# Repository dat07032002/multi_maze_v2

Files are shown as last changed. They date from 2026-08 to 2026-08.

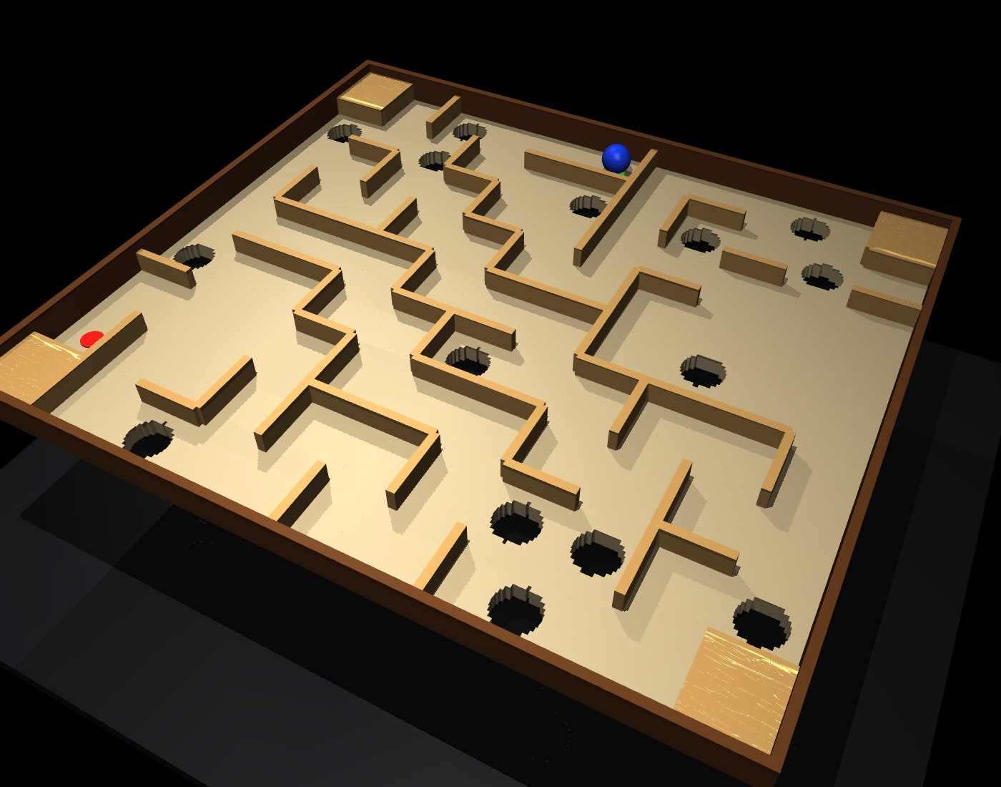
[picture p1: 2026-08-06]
maze_design/maze_final_iso.png

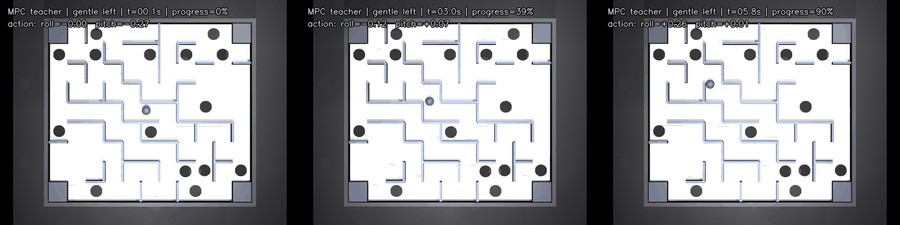
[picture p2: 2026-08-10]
tmp/pdfs/current_design_assets/gentle_left-mpc-teacher-strip.jpg

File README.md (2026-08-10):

# Multi Maze V2: board vision, maze design, and tilt servos

A ball-maze robot built from scratch, standalone Python, no ROS.

Six parts exist today:

- **Vision** -- a calibrated overhead camera and four AprilTags give the board's
  two tilt angles; a hybrid blue-colour/circle detector locates a 5.5 mm-radius
  marble in metric board coordinates.
- **Maze design** -- generators, a rescaler, an STL exporter, and validators for
  the printed 256 x 226 mm insert. See [`maze_design/README.md`](maze_design/README.md).
- **Servos** -- a from-scratch FEETECH STS3215 bus driver and command tools.
- **IMU and system identification** -- an ESP32 streams BNO086 tilt at 200 Hz,
  and `tools/sysid_actuator.py` measures the counts-to-angle mapping the servo
  contract needs. See [`firmware/esp32_imu/README.md`](firmware/esp32_imu/README.md).
- **Camera maze planning** -- the live image is rectified into board millimetres,
  segmented into walls and holes, inflated for the marble radius, and planned
  with clearance-aware A*.
- **Real model-based RL** -- safe random exploration collects real transitions,
  a probabilistic PyTorch ensemble learns dynamics on the local GPU, and CUDA
  CEM plans bounded tilt sequences. Training and checkpoint replacement happen
  between physical episodes; no simulator or sim-to-real transfer is used.

The main live application is standalone OpenCV and does **not** require ROS:

```bash
python3 tools/manual_tilt_angle.py
```

Press `z` while the board is level to save the angle reference. Press `q` or
`Esc` to quit.

## What the viewer reports

The window is camera-undistorted and displays:

- `alpha`: rotation about the board X hinge, in degrees;
- `beta`: rotation about the subsequent board Y hinge, in degrees;
- detected tag IDs and pose reprojection error;
- blue-marble centre `(x, y)` in millimetres and detector confidence;
- the magenta board boundary and metric coordinate frame;
- `O (0,0) mm` at the lower-left board corner, near tag 3;
- red `+X` toward the lower-right corner/tag 1;
- green `+Y` toward the upper-left corner/tag 0.

The ball position is its centre projected onto the plane `z = 5.5 mm`, not the
point where it touches the board.

## Current hardware and calibration

| Item | Current value |
| --- | --- |
| Camera | See3CAM_24CUG, auto-selected when available |
| Capture | 1920 x 1200 MJPG, resized uniformly to 1280 x 800 |
| Calibration model | Kannala-Brandt fisheye |
| Calibration RMS | 0.390 px over 88 views / 5108 points |
| Board | 256 x 226 mm |
| Tags | Four 18 mm `tag36h11` tags, IDs 0–3 |
| Marble | Blue, 5.5 mm radius |
| Pose requirement | Four known tags by default |
| Pose rejection | Reprojection RMS greater than 4 px |
| Tilt servos | Two FEETECH STS3215, ids 1 and 2, 1 Mbps on `/dev/ttyUSB0` |
| Servo mode | Position (register 33 = 0), 0-4095 counts over 360 deg |
| IMU | SparkFun BNO086, I2C on ESP32 GPIO16/17, game rotation vector @ 200 Hz |
| IMU link | ESP32-D0WD-V3 on CP2102, 115200; ports resolved by USB id |
| Directional calibration | alpha +0.00477 deg/count on servo 2; beta -0.00442 on servo 1 |
| Level at | servo 1: 2173 counts; servo 2: 2013 counts |
| Commandable tilt | ±4.0°, calibrated headroom ±5.42° / ±5.78° |
| Mechanical travel | roll ±7.00°, pitch ±8.36° |
| Backlash (operational) | **~1.35°** — the dominant error by ~7x |
| Command resolution | 40 counts (~0.19°) practical floor; under 20 is unusable |

The checked-in tag coordinates in
[`calib/board_tags.json`](calib/board_tags.json) are **derived from the maze
layout's tag pads, not caliper-measured** (`"measured": false`). Tags are glued
to the top of the corner pads, so `z_m = 0.011`: the pad top is 8 mm above the
playing surface and the tag is 3 mm thick. All four shift equally, so alpha and
beta are unaffected, but marble coordinates are -- the ray/plane intersection
depends on that height. Measuring the installed tags remains the route to
absolute accuracy.

The saved zero in [`calib/board_zero.json`](calib/board_zero.json) is specific
to the current camera pose. Re-zero after the camera, board mount, or lens has
moved.

## Installation

Python 3.10 was used during development. On a regular Python environment:

```bash
python3 -m venv .venv
source .venv/bin/activate
python3 -m pip install -r requirements.txt
python3 -m pytest -q
```

OpenCV must contain `cv2.aruco`; this is why the requirements use the contrib
distribution. The main live viewer accesses the camera directly with OpenCV.
The older calibration/monitoring tools that import `rclpy` additionally require
a sourced ROS 2 installation and `cv_bridge`.

Install the optional local-GPU RL dependencies after the NVIDIA driver is
healthy:

```bash
python3 -m pip install -r requirements-rl.txt
python3 tools/rl_preflight.py
```

## Everyday commands

Run the combined angle and ball viewer:

```bash
python3 tools/manual_tilt_angle.py
```

Cross-check the camera angles against the BNO086 while also viewing ball
coordinates. With the powered board physically level, press `z` once to save a
joint reference, then hold several positive and negative tilts on each axis:

```bash
python3 tools/camera_imu_check.py
```

The checker records comparisons only while the IMU is settled and reports
bias, RMSE, and maximum error when it exits. It also displays `FUSED`: IMU
increments provide the low-latency motion estimate and valid camera poses pull
that estimate back to an absolute reference with a 0.5 s time constant. Camera
residuals above 2° are rejected by default. Both values are configurable with
`--fusion-time-constant` and `--fusion-camera-gate`.

Drive the calibrated board from the keyboard while logging camera, IMU, and
fused angles, their difference, servo counts, targets, and pose quality:

```bash
python3 tools/keyboard_motor_compare.py
```

Use `A/D` for alpha, `S/W` for beta, `0` for the captured level position, and
`q` to quit and release torque. Runs are stored under
`artifacts/keyboard_compare/`.

Use the validated direction-dependent motor calibration when precise static
positioning matters:

```bash
python3 tools/keyboard_motor_compare.py \
  --directional-calibration calib/directional_motor.json \
  --fused-trim
```

This table is tied to the saved joint zero and must be regenerated after
re-zeroing or changing the linkage. Fit a new candidate from a settled fused
bidirectional run with `tools/fit_directional_motor.py <run-directory>`.
`--fused-trim` adds a slow static correction after each move: it waits for the
IMU to settle, corrects both axes through the measured coupled Jacobian, caps
each correction at 80 counts, and stops after at most six attempts. Its 0.10°
default tolerance is below the rig's measured 0.19° reliable command step.

Build a route from the maze that is physically under the camera, rather than
from a saved maze-design file:

```bash
# Use the detected blue ball as START and click the GOAL.
python3 tools/plan_camera_maze.py --click

# Or supply both endpoints in board millimetres.
python3 tools/plan_camera_maze.py \
  --start-mm 30 200 --goal-mm 220 25 --no-window
```

The mapper aligns 20 frames through the four AprilTags, rectifies the playing
surface at 2 pixels/mm, takes a temporal median, and segments yellow walls and
circular black holes. It plans on a 1 mm grid after inflating every obstacle by
the 5.5 mm ball radius plus a 0.5 mm safety margin. Clearance-weighted A* and
line-of-sight pruning produce 5 mm-spaced training waypoints. Each run writes
the top-down image, masks, route overlay, and metric `map.json` under
`artifacts/camera_maze/<timestamp>/`. Use `--auto-endpoints` only as a mapping
smoke test; training should specify the intended start/goal or click them.

Run continuous real-hardware training from an empty replay:

```bash
python3 tools/run_real_rl.py \
  --execute \
  --continuous-training \
  --fresh-replay \
  --policy explore
```

`--execute` opens the servo bus but does not move it. Wait for green health and
press Space once to authorize the first episode. `q`/Escape always levels the
board, releases torque, saves replay, and stops. The controller then operates
without a key press between ordinary episodes:

- fresh data uses smooth random targets over the full ±4° envelope;
- commands are independently clipped to ±4° and slew-limited to 0.5° per 5 Hz
  control step;
- the first dynamics model needs at least 300 total transitions and 120 with
  measured motion;
- dynamics bootstrap batches are balanced 50/50 between moving and stationary
  transitions so static samples cannot overwhelm the command response;
- after a model is available, four CEM episodes alternate with one random
  exploration episode;
- a CEM episode stationary for 3 s changes to `RECOVERY_EXPLORE` for the rest
  of that episode, without prescribing a hard-coded breakaway angle;
- every additional 100 transitions schedules another 50-epoch background
  update and activates it only at an episode boundary.

To resume, provide both the saved replay and latest completed checkpoint;
never select an update whose checkpoint was interrupted:

```bash
python3 tools/run_real_rl.py \
  --execute --continuous-training \
  --replay artifacts/rl/runs/<run>/replay_after_run.npz \
  --checkpoint artifacts/rl/runs/<run>/online_models/update_NNN/dynamics.pt \
  --policy cem
```

The live phases are operational state:

| Phase | Meaning |
| --- | --- |
| `EXPLORE` | scheduled full-range random data collection |
| `RL_EPISODE` | CEM is planning through the learned ensemble |
| `RECOVERY_EXPLORE` | CEM stayed stationary for 3 s; random recovery took over |
| `CONFIRMING_DROP` | detection is stale; the board is level while absence is debounced |
| `ARMED_FOR_RELOAD` | a real drop is confirmed; calibrated backward tilt is held |
| `FIXED_BRAKING` | the reappearing marble is being slowed |
| `RESET_SETTLING` | level board and speed below 12 mm/s are being confirmed |
| `TRAINING_WAIT` | reset is complete but an atomic model update is finishing |

Judge learning across episodes using maximum route progress minus episode-start
progress, cross-track error, return, goal count, and the fraction of CEM
episodes needing recovery. Validation loss alone is not proof that the physical
controller improved.

Select a camera explicitly or run without a GUI:

```bash
python3 tools/manual_tilt_angle.py --camera 2
python3 tools/manual_tilt_angle.py --zero-on-start --no-window
```

Record a new 500-frame detector dataset at 10 Hz:

```bash
python3 tools/record_ball_dataset.py --frames 500
```

Record even when only three tags are visible (diagnostics only):

```bash
python3 tools/record_ball_dataset.py --frames 500 --min-tags 3
```

Generated frames, masks, JSONL measurements, manifests, and summaries are saved
under `artifacts/ball_capture/<timestamp>/`. This directory is ignored by Git
because raw captures are large.

Bring up the IMU and capture the level reference (do this before any servo
moves, and before anything disturbs the plate):

```bash
python3 tools/imu_monitor.py --seconds 20        # noise and drop check
python3 tools/imu_monitor.py --capture-zero --check-torque-shift
```

Measure the servos against the IMU, then fit the contract:

```bash
python3 tools/sysid_actuator.py --dry-run        # preflight, commands no motion
python3 tools/sysid_actuator.py
python3 tools/fit_sysid.py artifacts/sysid/<stamp>/sysid.json
```

Run all synthetic tests:

```bash
python3 -m pytest -q
```

## How it works

### Board angle

1. Detect known AprilTag IDs in grayscale with OpenCV ArUco.
2. Acquire/recover tags on the native 1920 x 1200 frame with
   `CORNER_REFINE_APRILTAG`, then track them in small native-resolution ROIs;
   perform a periodic full scan every 15 frames.
3. Undistort tag pixels with the calibrated Kannala-Brandt camera model.
4. Match pixels to each tag's known board-frame corners.
5. Solve the board-to-camera transform with iterative `solvePnP`.
6. Compare rotation with the saved level reference.
7. Extract angles using the simulator-compatible hinge order
   `R = Rx(alpha) @ Ry(beta)`.

### Marble position

1. Project the board boundary into the image and reject pixels outside it.
2. Exclude expanded tag footprints, which can look blue under the camera's
   fixed white balance.
3. Form broad and strict blue masks using HSV plus BGR channel separation.
4. Clean small mask noise and score contour candidates by strict-blue coverage,
   circularity, and expected projected radius.
5. Use Hough-circle edge recovery when a marble touching a rail or tool merges
   into a larger blue component. When colour already identifies the marble,
   refine the circle only in a small local crop rather than scanning the board;
   while no colour anchor exists, throttle expensive board-wide recovery to
   every fifth frame.
6. Prefer candidates near the previous valid position and reject impossible
   frame-to-frame jumps.
7. Convert the chosen distorted pixel to a calibrated ray and intersect it with
   the board-frame marble-centre plane `z = radius`.
8. Apply an exponential moving average to the reported board `(x, y)`.

Detection remains on the calibrated raw frame. The viewer image and every
overlay are mapped into the same undistorted pixel space, so visualization does
not alter the measurement path.

### Board angle from the IMU

A second, independent path to the same two angles, used as ground truth for
system identification because it samples far faster than the camera.

1. The ESP32 reads the BNO086's game rotation vector at 200 Hz over I2C.
2. Quaternions cross the link as Q14 fixed point in a 17-byte CRC-checked frame.
3. The host converts quaternion to rotation matrix and extracts alpha and beta
   with the **same** `angles_from_rotation` the camera path uses, so the two are
   directly comparable rather than two conventions that happen to agree.
4. Angles are reported relative to a level reference captured in place, using
   `zero.T @ current` -- the convention `BoardPoseEstimator` already uses.

Dropped frames are counted and surfaced, never interpolated over: a missing
report during a step response is a hole in the measurement, not a value to
invent.

### Actuator system identification

`tools/sysid_actuator.py` measures what the servo contract refuses to guess, in
a deliberate order:

1. **Axis discovery** -- move each servo alone and see which angle responds.
   Produces the sign, the axis assignment, and the 2x2 cross-coupling matrix.
   Runs first because nothing else is safe until the signs are known, and
   because significant coupling would invalidate the contract's independent-axis
   shape before any effort is spent fitting it.
2. **Static sweep** -- a load-guarded staircase gives gain, offset, and the
   linearity residual.
3. **Hysteresis** -- the same staircase in reverse gives backlash and deadband.
4. **Step response** -- unramped steps at 200 Hz give latency, rise time, and
   peak rate, with half the measured link round-trip subtracted so the latency
   describes the servo rather than the USB cable.

`tools/fit_sysid.py` writes the contract only when the measurement supports the
linear model it encodes. Failing linearity, plausibility, or coupling checks
produces `measured=False`, which keeps `angle_to_counts` raising -- a contract
that claims to be measured and is not would be worse than one that refuses.

## Repository layout

```text
calib/                         camera, board, zero, and printable tag files
contract/servo_contract.py     policy action -> board angle -> servo counts
docs/PROJECT_STATUS.md         work completed, evidence, limits, next steps
firmware/esp32_imu/            ESP32 sketch streaming BNO086 tilt
tag_vision/core/board_geometry.py
tag_vision/core/board_pose.py
tag_vision/core/ball_detection.py
tag_vision/core/angle_fusion.py complementary camera + IMU angle estimator
tag_vision/hardware/sts3215.py FEETECH bus driver
tag_vision/hardware/motion.py  load-guarded point-to-point moves
tag_vision/hardware/imu.py     BNO086 frame reader
tag_vision/control/tilt.py     board angle -> counts, backlash fed forward
tag_vision/planning/           camera maze map + clearance-aware route planner
tag_vision/rl/                 replay, task, safety, dynamics, CEM, exploration
tools/manual_tilt_angle.py     standalone live viewer
tools/camera_imu_check.py      settled camera-vs-IMU angle cross-check
tools/keyboard_motor_compare.py keyboard motor control + angle comparison log
tools/plan_camera_maze.py      live metric map and route generation
tools/run_real_rl.py           continuous real-hardware MBRL runner
tools/train_rl_dynamics.py     offline/background ensemble trainer
tools/rl_preflight.py          GPU, geometry, calibration, and port checks
tools/record_ball_dataset.py   standalone data recorder
tools/imu_monitor.py           IMU bring-up and level-zero capture
tools/sysid_actuator.py        actuator system identification
tools/fit_sysid.py             sysid run -> servo calibration
tools/validate_backlash.py     measures whether compensation actually helps
tools/*.py                     calibration, tag, servo, and ROS utilities
test/                          synthetic geometry, pose, detector, IMU, fit tests
```

## Known limitations

- Four coplanar tags give low noise, but out-of-plane tilt remains more weakly
  conditioned than translation. Known-angle physical validation is still
  required before treating angle values as ground truth.
- Using three tags can keep a pose alive during occlusion, but the tested
  `(0,1,3)` subset shifted alpha/beta by roughly `+0.47°/+0.20°` relative to
  the four-tag solution. The production default therefore requires four tags.
- Blue appearance thresholds were tuned for this camera and lighting. Major
  lighting, exposure, white-balance, board-colour, or marble-colour changes
  require fresh validation.
- The 98% recovery measured during development was an unlabeled replay with a
  blue handling tool present. It demonstrates improved recovery, not a final
  true-positive rate. A labeled, freely moving marble dataset is the next
  validation milestone.
- There is no fixed-frame tag. Moving the camera invalidates the saved level
  reference and requires pressing `z` again.
- The 2026-08-10 camera cross-check covered commanded ±4° on both axes. At the
  four endpoints camera-vs-IMU RMSE was 0.145° alpha and 0.109° beta. The
  independent sensors therefore agree well enough for complementary fusion,
  but both also exposed direction-dependent mechanical lost motion that the
  current single linear motor mapping cannot remove.
- **The calibration is valid over the range it was swept** (±1200 counts,
  roughly ±5.5°) and must not be extrapolated past it. Within that range a
  straight line holds well -- 12° of span at under 2% residual -- so the
  nonlinear form once thought necessary is not.
- **Absolute level is repeatable to about 0.4°.** The fitted centre moved 85
  counts between two consecutive sweeps with no mechanical change. Relative
  moves are considerably more trustworthy than absolute pose.
- **Commands under 20 counts do not reliably keep their sign.** 40 counts
  (~0.19°) is the practical floor, 80 is repeatable to a few percent. Any
  controller or policy step finer than that is commanding noise.
- **Backlash is the dominant error, at ~1.35° unconditioned.** That is roughly
  seven times the model residual (0.23°), the command resolution (0.19°) and the
  IMU noise (0.006°) combined. It is deterministic, not random: approached
  consistently from one side the axes repeat to 0.03°. Static positioning should
  condition its approach and gets a 40x more precise result; dynamic control
  must feed the lost motion forward instead -- about 277 counts on roll, 269 on
  pitch, injected at a direction reversal. **Simulators must use the
  unconditioned figure**, or the model will be far more precise than the board.
- The IMU level zero is captured **in place**, relying on the board being
  physically level with the IMU already mounted. That removes the need to
  measure a mount offset, but it is perishable: bumping the plate or re-mounting
  the sensor invalidates it, and re-levelling by eye reintroduces exactly the
  offset the approach avoids.
- The straight line in `AxisCalibration` holds within ±1.4°, where the model
  error (0.057°/0.071° rms) is well under one 40-count command. It is not a
  general claim about the linkage, which is a crank and loses authority further
  out; a nonlinear form is the eventual answer if the maze needs more tilt.
- **The ESP32 serial link is unreliable above 115200 and re-delivers frames.**
  Flash reads at 921600 and 460800 both stalled at exactly `0x6000`, and over 5 s
  the port yielded 1298 frames' worth of bytes when the device had sent 1000.
  The reader deduplicates on `(seq, esp_micros)`; telemetry and reflashing stay
  at 115200.
- The See3CAM negotiates 1920×1200 MJPEG at 60 FPS through direct V4L2, but the
  sequential vision pipeline processes roughly 16–19 FPS while doing pose,
  ball, route, viewer, and occasional CEM work. This is sufficient for the
  current 5 Hz controller. Camera acquisition FPS is not replay frequency.
- `--tag-detection calibrated` is an experimental A/B option that runs AprilTag
  detection on the resized 1280×800 frame. A live 2026-08-10 test improved
  processing from 22.7 to 26.0 FPS but produced 0 accepted poses at the 4 px
  reprojection gate in that view; production remains native 1920×1200 tag
  detection. The camera's native 1280×720 mode has a different aspect ratio and
  requires a separate intrinsic calibration, level zero, maze map, and caliper
  validation.
- Early online models trained from mostly stationary replay falsely predicted
  motion at zero command and selected small CEM actions. First activation is
  now gated on 120 moving transitions, training bootstraps are balanced,
  periodic exploration remains active, and sustained stationary CEM control
  falls back to random recovery. Physical episode progress remains the
  acceptance metric.

See [the project status](docs/PROJECT_STATUS.md) for detailed measurements and
the remaining validation plan.

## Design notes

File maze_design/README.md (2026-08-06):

# Maze design

## Current maze

**`maze_256x226`** — 256 × 226 mm, 15 holes, 118 waypoints, route 1023 mm.
This is the one the rest of the project targets.

| File | What |
| --- | --- |
| `maze_256x226.json` | **Source of truth.** Layout in metres, origin lower-left. |
| `maze_256x226_roles.json` | Hole roles by index: 14 `block`, 1 `dodge` |
| `maze_256x226.stl` | Printable, single colour, millimetres |
| `maze_256x226_floor.stl` | Plate only, z 0 → 3 mm |
| `maze_256x226_walls.stl` | Walls and tag pads, z 3 → 11 mm |
| `maze_256x226.png` | Top-down render |
| `maze_256x226_3d.png` | Shaded 3-D render |

Everything but the JSON is regenerated by the pipeline below, so treat the STLs
and PNGs as build output.

## Pipeline

```bash
python3 maze_design/rescale_maze.py --width 256 --height 226   # layout
python3 maze_design/export_stl.py  maze_design/maze_256x226.json          # one body
python3 maze_design/export_stl.py  maze_design/maze_256x226.json --split  # two colours
python3 maze_design/check_stl.py   maze_design/maze_256x226.json --split  # validate
python3 maze_design/render_maze.py maze_design/maze_256x226.json          # 2-D
python3 maze_design/render_3d.py   maze_design/maze_256x226.stl           # 3-D
```

`check_stl.py` is not optional. Mesh statistics alone cannot tell a correct maze
from one whose holes were never cut, and an earlier export shipped 15 hole
surrounds with inverted normals while passing every structural test. It
ray-casts against the layout and requires a **positive** winding, which is what
catches an inside-out solid.

## Geometry

| | |
| --- | --- |
| Playing area | 256 × 226 mm, 11 × 9 cells |
| Cell pitch | 23.273 × 25.111 mm |
| Corridor | 20.273 × 22.111 mm clear |
| Walls | 3 mm thick, 8 mm tall |
| Floor | 3 mm; total print height 11 mm |
| Holes | 15, radius 7.5 mm |
| Tag pads | Corner cells, solid, top at 11 mm |
| Ball | 5.5 mm radius is authoritative; the layout's 6.0 mm is design margin |

Tags are **glued** to the pad tops, so the tag face sits 11 mm above the playing
surface — that is `z_m` in `calib/board_tags.json`. `--pocket` cuts a recess
instead (face at 8 mm), but it is not the default: the pad is one cell wide, so
a pocket for a 23 mm tag leaves 0.14 mm of frame and, because corner pads sit on
the board edge, opens to the outside.

## Why rescale rather than regenerate

`maze_final.json` was **not** produced by `generate_maze.py` — that script emits
`maze_v1.json` with 23 horizontal wall runs against the final's 76. The pipeline
that made it is not in this repository, so regenerating from seed 1626 yields a
different maze. `rescale_maze.py` scales the existing layout instead, which
keeps the topology identical.

Positions scale; wall thickness, wall height, hole radius, and ball radius do
not — those are set by the printer and the marble. The corridors absorb the
difference.

## Historical files

Kept for provenance, not used by anything current:

- `maze_final.*` — the 259 × 229 predecessor `maze_256x226` was scaled from
- `maze_print*.stl` — its STLs, scaled in **metres**; a slicer reads them as a
  0.26 mm speck
- `print/maze_final/` — an older 17-hole bundle, superseded. Its `route.json`
  (122 points) does not match any current layout
- `base_1626.*`, `maze_v1.*`, `sample_1..12.*`, `samples*.png` — earlier
  candidates and contact sheets

## Broken scripts

`view_maze.py`, `orbit_maze.py`, `playtest_maze.py`, and `generate_samples.py`
`sys.path.insert` into `~/Desktop/TAG/Multi-maze` for MuJoCo and a route
planner. That project is out of scope for this repository, so these do not run.
They are kept only as a reference for what a playtest harness needs to do; a
replacement belongs with the simulator work.

`generate_maze.py` raises `NameError: pick_seed` if run directly — its
`__main__` calls a seed-search function that is not in the file. The `build()`
and `carve()` functions it defines are fine and importable; only the entry point
is broken. Nothing currently depends on it, since the live maze comes from
`rescale_maze.py`.

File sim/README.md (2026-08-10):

# Simulation

MuJoCo model of the printed 256 x 226 mm maze. Milestone M0 of the plan: the
board geometry and a ball-on-plate model trustworthy enough to build on.

```bash
python -m sim.mjcf_builder --out board.xml   # compile, print geom counts
python -m sim.render_maze                    # four PNGs into artifacts/sim_preview
python -m sim.view_maze                      # interactive; arrows tilt, R resets
python -m sim.view_maze --flat               # bare plate, no walls or holes
python -m pytest test/test_physics.py test/test_mjcf_builder.py -q
```

`python`, not `python3`: the simulator runs on the Windows development machine,
where `python3` is a Microsoft Store alias that is not installed. The rest of
the repo says `python3` because the hardware tools run on the Linux box with the
servos and camera attached.

| File | What |
| --- | --- |
| `parameters.json` | every constant, each marked `measured` / `derived` / `design` / `assumed` |
| `mjcf_builder.py` | `maze_256x226.json` -> MJCF |
| `board_state.py` | frame conversions, rate-limited tilt driver, restitution measurement |
| `actuator.py` | commanded angle -> realised plate angle, on the measured chain |
| `analytic_model.py` | closed-form double integrator, used off the simulator |
| `route.py` | arc-length resampled route, projection, lookahead, clearance |
| `rollout.py` | closed loop: measure -> filter -> predict -> control -> act |
| `run_baseline.py` | the analytic baseline's score, and a track overlay |
| `render_maze.py` | offscreen review renders |
| `view_maze.py` | interactive viewer |

## What the model contains

847 geoms: 795 floor boxes with the 15 holes cut out, 42 walls, 4 tag pads, 4
frame rails, a catch tray and the ball. Roughly 46 000 physics steps/s on one
core, so a 20 Hz control step costs about 1 ms and a million env steps is 18
minutes single-core.

Three decisions worth knowing before changing anything:

**Holes are real gaps, not a scripted termination.** MuJoCo has no boolean
subtraction, and a mesh with holes cut in it collides as its convex hull -- a
solid slab. So the floor is decomposed into y-bands with each hole's x-interval
subtracted. Band edges are placed at equal steps in *half-width* rather than
uniformly in y, because a circle's half-width slope runs away at its top and
bottom: uniform 2 mm -> 0.25 mm strips cost 6.8x the boxes and improved the rim
only from 4.50 mm to 1.92 mm, while the current scheme holds 0.419 mm against a
0.5 mm budget.

**The cut errs outward, never inward.** A band is removed wherever any part of
it falls inside the circle, so no sliver of floor pokes into a hole for the ball
to catch on. Measured intrusion is 0.

**Tilt is applied with a rate limit, and sets `qvel` as well as `qpos`.** Writing
`qpos` alone leaves the contact solver seeing a stationary plate. Commanding a
step change is worse: an 8 degree jump in one millisecond launches the ball
about 10 mm into the air with no contacts at all. `TiltDriver` slews at the
measured 6.9 deg/s roll and 8.2 deg/s pitch. The full actuator model -- dead
time, backlash, quantisation -- arrives in M1.

## The actuator model (M1)

`request -> tilt.py compensator -> counts -> [dead time -> lag and rate limit ->
linkage backlash] -> plate`. The compensator is imported from
`tag_vision.control.tilt`, not reimplemented, so sim and hardware cannot drift.

Against the rig:

| | modelled | measured | |
| --- | ---: | ---: | ---: |
| roll latency (5 %) | 184.0 ms | 184.9 ms | −0.5 % |
| roll rise (10-90 %) | 256.0 ms | 256.1 ms | −0.0 % |
| pitch latency (5 %) | 150.0 ms | 150.3 ms | −0.2 % |
| pitch rise (10-90 %) | 229.0 ms | 229.6 ms | −0.3 % |
| roll error, compensation off | 0.880° | 0.876° | +0.5 % |
| roll error, compensation on | 0.280° | 0.261° | +7.3 % |
| pitch error, compensation off | 0.622° | 0.427° | +45.6 % |

Three things worth knowing before changing it:

**Backlash goes last, after the lag.** The slack is in the linkage, so the shaft
moves smoothly and the plate picks up only once the slack is taken up. That is
what makes a reversal cost ~277 counts of servo travel before the plate moves at
all -- and makes a reversal *smaller* than 1.35° move it not at all. Both are
pinned by tests, because they are precisely what the action-rate penalty is
priced against.

**`step_latency_s` is not the dead time.** sysid defines latency as the 5 %
crossing, so a first-order response spends `tau·ln(1/0.95)` of it just climbing
to 5 %. Using 0.185 s as pure dead time would put the modelled crossing 3.2 %
late for a knowable reason. The pure dead times are 0.17896 s and 0.14495 s.

**Quantisation is one count plus a deadband, not a 40-count grid.** The servo
takes any integer count; 40 counts is the smallest reliable *change*. What is
real is the measured deadband -- 6.4 counts roll, 27.9 pitch.

**The slew ceiling is the one consequential unknown left.** `max_rate` is
`max()` of the sample-to-sample rate during the step runs, so it is a floor on
capability, not a ceiling, and biased high besides. sysid only stepped
0.195-0.584°, where a rate limit changes the response by **0 ms**; a policy
commands up to 8° swings, where it is worth **275 ms on a 4° step** — comparable
to the whole dead time. `actuator.slew_limit_scale` (1.0 = clamp at the observed
rate, 5.0 = effectively unclamped) exists so this is randomised at M4 rather than
asserted. One 10-minute rig run settles it:
`tools/sysid_actuator.py --step-counts 40 80 120 400 800`.

## The analytic layer and the baseline (M2)

Between contacts each axis is an independent double integrator,
`x'' = 7.007·sin(beta)`, plus a lumped linear damping. MuJoCo agrees with it to
**0.138 mm over the 250 ms prediction horizon** — 0.5 mm at 500 ms — which is
what the predictor, the Kalman filter and the baseline all rely on.

```bash
python -m sim.run_baseline --seeds 10 --render artifacts/baseline
```

| | |
| --- | ---: |
| success | **10/10** |
| fell in a hole | 0/10 |
| route completion | 99.4 % mean, 99.3 % worst |
| cross-track | 2.84 mm mean, 11.44 mm worst |
| time to goal | 53.0 s (budget 60 s) |

**This is the bar RL has to clear at M3 and M4.** Two things about it matter as
much as the success rate. The working region is narrow — 45 mm/s drops to 8/10,
cross-track gain 4.0 to 7/10 — because a fixed law has very little margin
against 240 ms of loop delay, which is most of the argument for learning one.
And 53 s of a 60 s budget is not much room: the baseline is slow because it has
to be.

**`ball.linear_damping` was discovered here, not assumed.** Fitting
`dv/dt = A·sin(beta) − c·v` to the simulator recovers `A = 7.0555` against the
analytic 7.0071 — the gain is right to 0.7 % — and `c = 0.202 /s`. Without that
term the analytic model overshoots MuJoCo by 7.8 % at 0.4° and 2.2 % at 4°,
worst when the ball is slow, which is exactly where a controller is trying to
hold it still. It is derived from the *sim*, so M5 must re-fit it from a real
coast-down.

## Known limits

- **Wall impacts penetrate ~0.22 mm** at 0.30 m/s, against 0.0025 mm for rolling
  contact. Larger than the 0.1 mm the M0 plan asked for; it is a property of the
  contact solver at a 1 ms timestep and is bounded by a test at 0.3 mm.
- **Restitution is emergent, not declared.** MuJoCo takes a solref damping
  ratio, so `ball.wall_restitution` is a target realised through
  `sim.wall_dampratio`. Read the achieved value with
  `board_state.measure_restitution`; M5 fits the damping ratio to a real bounce.
- **Pitch backlash is modelled flat at 1.35°, and it is position-dependent.**
  Real pitch runs ~1.5° mid-range against 0.4-0.6° near the extremes, so over the
  ±2° validation sequence the model reads 0.622° where the rig reads 0.427° —
  an effective 0.91° out there. The flat figure is what `PROJECT_STATUS.md`
  mandates for simulation, and erring high is the safe direction: a policy
  trained against more lost motion than the rig has is over-prepared, one
  trained against less arrives expecting authority that is not there.
  Tabulating the position dependence is on the M5 list.
- **Four parameters are still assumed**, all flagged in `parameters.json`:
  rolling resistance and wall restitution (both dominant, both fitted at M5),
  floor sliding friction and ball density (both low-consequence -- the ball
  never slips, and `a = (5/7) g sin(theta)` is mass-independent).
- The rolling-resistance model costs about 3 % of the gravity drive at 4
  degrees. Physics is validated against `(5/7) g sin(theta)` with rolling
  resistance switched off, where it agrees to 0.8 %.

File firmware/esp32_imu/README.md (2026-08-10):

# ESP32 BNO086 tilt telemetry

Streams board tilt from a SparkFun BNO086 to the host, for actuator system
identification. The host side is [`tag_vision/hardware/imu.py`](../../tag_vision/hardware/imu.py);
the wire format is defined here and the two must change together.

## Hardware

| Qwiic | Signal | ESP32 |
| --- | --- | --- |
| Red | 3.3 V | 3V3 |
| Black | GND | GND |
| Blue | SDA | A4 / SDA |
| Yellow | SCL | A5 / SCL |

The IMU now uses a separate **Arduino Nano ESP32** so the original ESP32 can run
the marble reload firmware at the same time. The FEETECH servo bus is the CH340
at `/dev/ttyUSB0` — never point a flashing tool at it.

The Nano enumerates persistently as
`/dev/serial/by-id/usb-Arduino_Nano_ESP32_206EF1320C94-if01`. Host tools resolve
the `Arduino_Nano_ESP32` identity automatically instead of assuming a tty
number.

The firmware uses the board core's `SDA` and `SCL` names rather than raw ESP32
GPIO numbers. This keeps A4/A5 correct under either Nano ESP32 pin-numbering
mode.

## Build

Arduino IDE or `arduino-cli`, with:

- board: ESP32 Dev Module
- library: **SparkFun BNO08x Arduino Library**
- the original firmware on this chip was built against arduino-esp32 **3.3.10**
  (ESP-IDF v5.5.4); anything recent will do for this sketch

```bash
arduino-cli compile --fqbn esp32:esp32:esp32 firmware/esp32_imu
arduino-cli upload  --fqbn esp32:esp32:esp32 -p /dev/ttyUSB1 firmware/esp32_imu
```

## Wire format

```
[0xA5][0x5A][type][len][payload...][crc8]
```

CRC-8 is Dallas/Maxim, polynomial `0x31`, over `type`, `len`, and payload — not
the sync word, which is what the host resynchronises on after a dropped byte.

| type | name | payload |
| --- | --- | --- |
| `0x01` | sample | `u32` micros, 4× `i16` quaternion (Q14, i/j/k/real), `u8` accuracy, `u8` seq |
| `0x02` | pong | `u32` echoed token, `u32` device micros |
| `0x03` | status | ASCII, bring-up messages |

Host commands: `'P'` + 4-byte token requests a pong; `'R'` re-enables reports.

### Why these choices

**Binary, not CSV.** This USB link is demonstrably unreliable above 115200 —
flash reads at 921600 and 460800 both stalled at exactly `0x6000`, and one
512 KB chunk needed a retry even at 115200. So the baud is fixed at 115200 and
the frame has to fit inside it. CSV quaternion floats run ~60 B, which at 200 Hz
is 12 kB/s against roughly 11.5 kB/s usable — over budget, and the failure mode
is silent backpressure appearing as jitter in exactly the latency numbers sysid
exists to measure. The 17-byte frame is 3.4 kB/s.

**Game rotation vector, not the fused one.** Game rotation vector is
gravity-referenced but ignores the magnetometer. Two STS3215 servos drawing
current a few centimetres away disturb any magnetometer-fused heading, and tilt
is the one thing that must stay clean. Yaw drift does not matter here.

**Q14 quaternions.** That is the BNO's native scaling, so this converts back to
it rather than adding a second quantisation. The resulting angle resolution is
about 0.007°, asserted in [`test/test_imu.py`](../../test/test_imu.py) and far
below the sensor's own noise.

**Sequence numbers are generated here, not taken from SH-2.** They therefore
detect frames lost between this device and the host — serial overrun, a dropped
byte resyncing the parser — which is what this link is actually prone to. A
report the BNO itself skipped shows up instead as a gap in the micros timestamp,
which is why the timestamp is per-sample rather than inferred from the rate.

## Restoring the original firmware

The firmware that shipped on this board is backed up and **restore-tested** —
written back and read out again with matching hashes:

```
artifacts/esp32_backup/20260806_140245/
  flash_full_4MB.bin    sha256 770a1f9faaba1c33...
  manifest.json         chip, flash, partitions, provenance
```

```bash
esptool --port /dev/ttyUSB1 --baud 115200 write-flash 0x0 flash_full_4MB.bin
```

Use 115200. Higher rates fail on this link.

That image was built elsewhere (`/mnt/ssd2/trungbao-home/…`) and contains no
BNO08x driver, so it is not a predecessor of this sketch — it is someone else's
work that happened to be on the chip.

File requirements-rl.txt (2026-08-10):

# Install only after tools/rl_preflight.py reports a healthy NVIDIA driver.
# Select the CUDA wheel using the official PyTorch installer for this machine.
torch>=2.2

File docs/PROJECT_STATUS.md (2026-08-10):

# Multi Maze V2 project status

Last updated: 2026-08-10

> **Scope note.** Early sections began as a vision log and parts predate the
> 2026-08-06 rescale to a 256 x 226 mm board. Later sections cover the complete
> physical stack. Numbers measured on the 259 x 229 mm board (reprojection,
> angle noise, detection rates) were not re-taken and remain indicative. See
> [`../maze_design/README.md`](../maze_design/README.md); for the servo stack
> see the repository README.

## Scope

The initial milestone was reliable state estimation for a manually tilted maze
board:

```text
camera frame
  -> four-tag board pose
  -> zero-relative alpha/beta
  -> board-constrained blue-marble detection
  -> metric marble centre (x, y)
```

That perception contract now feeds camera-derived maze planning, fused motor
control, automatic physical reload, and continuous real model-based RL. The
coordinate conventions were retained throughout, so recorded state remains
compatible across those layers.

As of 2026-08-06 a second state-estimation path exists: a BNO086 IMU on an
ESP32, streaming board tilt at 200 Hz. It is not a replacement for the camera --
it gives angle only, not marble position -- but it samples fast enough to
measure actuator dynamics, which the camera at 10-30 Hz does not. See
[Actuator system identification](#actuator-system-identification) below.

## Coordinate and angle conventions

The moving board frame is:

- origin `(0,0,0)` at the physical lower-left board corner when viewed from
  above, adjacent to tag 3;
- `+X` right toward tag 1;
- `+Y` up toward tag 0;
- `+Z` out of the board surface;
- width 256 mm and height 226 mm.

The marble output is the centre `(x,y)` in this frame. Ray/plane intersection
uses `z = 5.5 mm` because the marble radius is 5.5 mm.

Angle order matches the simulator's two nested hinges:

```text
R = Rx(alpha) @ Ry(beta)
alpha = atan2(R[2,1], R[1,1])
beta  = atan2(R[0,2], R[0,0])
```

The result is relative to a rotation captured while the board is level. It is
not an absolute gravity reference.

## Work completed

### Camera calibration

- Built AprilGrid generation, capture, calibration, scaling, and validation
  tools.
- Compared pinhole/radial-tangential and Kannala-Brandt models.
- Selected the Kannala-Brandt calibration: 0.390 px RMS versus 0.808 px for the
  pinhole fit.
- Calibrated at 640 x 400 and uniformly scaled intrinsics to the working
  1280 x 800 image; the camera captures native 1920 x 1200 with the same aspect
  ratio before resizing.
- Added a focus-assist utility and live tag monitor.

### Board geometry and pose

- Defined the board frame and per-tag 3-D corners (259 x 229 mm at the
  time; rescaled to 256 x 226 mm on 2026-08-06).
- Added per-tag in-plane rotation so the installed tag orientations map to the
  correct ArUco corner order.
- Recorded installed layout:

  | ID | Location | Rotation |
  | --- | --- | ---: |
  | 3 | top-left | +90° |
  | 1 | top-right | 180° |
  | 2 | bottom-left | +90° |
  | 0 | bottom-right | -90° |

- Added geometry validation, known-ID filtering, fisheye point undistortion,
  iterative PnP, reprojection RMS, simulator-compatible angle extraction, and
  saved zero rotation.
- The original live-rig benchmark selected `CORNER_REFINE_CONTOUR` at about
  1.84 px median reprojection and 0.016°/0.006° static alpha/beta noise. That
  result was superseded after the installed tags changed; see the 2026-08-10
  re-verification below.
- Added a standalone camera viewer so missing ROS (`rclpy`) no longer blocks
  angle measurement.
- Added full-frame undistortion and a board boundary/origin/+X/+Y overlay.
- Re-verified the installed ID/rotation map on 2026-08-10 and switched corner
  refinement to `APRILTAG`: 76% complete four-tag poses versus 3% for
  `CONTOUR`, 1.92 px median reprojection, and about 0.007° static noise.
- Added `tools/camera_imu_check.py` for joint camera/IMU zeroing, settled-pose
  error statistics, and dropout-tolerant complementary fusion. The physical
  commanded ±4° cross-check completed on 2026-08-10: endpoint camera-vs-IMU
  RMSE was 0.145° alpha and 0.109° beta, with 98.92% endpoint tag-pose uptime.

### Camera + IMU fusion, 2026-08-10

`tag_vision/core/angle_fusion.py` integrates each unique BNO086 angle increment
once, then applies valid AprilTag poses as a slow absolute correction (0.5 s
default time constant). Per-axis camera residuals above 2° are rejected. The
fused estimate remains live through tag recovery frames and is logged by
`tools/keyboard_motor_compare.py` as `fused_alpha_deg` and `fused_beta_deg`.

The same test exposed why motor recalibration must be directional. Returning
the encoder to the captured zero count after beta −4° left the physical plate
at camera −1.081° / IMU −0.999°. A single centre plus counts/radian gain cannot
represent that state. The next calibration must capture fresh level counts,
sweep each servo upward and downward across the operating range, and fit the
two branches plus reversal lost motion before validating repeated zero returns.

That directional calibration was subsequently measured and validated. The
piecewise inverse is stored in `calib/directional_motor.json`; the complete
source data remains in `artifacts/keyboard_compare/20260810_121136`. Against
the old linear map, mean primary-axis error at the tested ±4° endpoints fell
from about 0.49° to 0.10°. The final return-to-zero error fell from about 1.23°
vector magnitude to 0.12°. Remaining error is dominated by cross-axis coupling
(up to about 0.35° during the alpha sweep), not camera/IMU noise.

### Settled fused trim, 2026-08-10

`tag_vision/control/fused_trim.py` now closes that remaining static error after
the directional feedforward move. It waits for a settled fused measurement,
maps the two-axis error through the inverse measured 2×2 Jacobian, holds an axis
that is already within tolerance, caps a correction at 80 counts, and stops
after six attempts. This is a bounded setpoint trim, not a continuously active
PID, so it cannot integrate indefinitely inside the backlash band.

Hardware validation across +4/0/−4/0 on both axes produced worst primary-axis
error 0.080° and worst cross-axis error 0.056° at the four endpoints. Final zero
was alpha −0.038° / beta +0.080°. The production tolerance is 0.10°, below the
rig's measured 0.19° reliable command resolution. The strict 0.08° validation
run is in `artifacts/keyboard_compare/20260810_122915`.

### Blue-marble detection

- Added a board-projected region of interest with distortion-aware sampled
  edges.
- Excluded expanded, known tag regions to suppress blue-cast black borders.
- Tuned broad and strict HSV/BGR blue masks for the installed camera.
- Added morphology, contour/ellipse fitting, circularity, expected-size, and
  strict-colour scoring.
- Added pose-aware pixel-to-board conversion using a ray intersection with the
  marble-centre plane.
- Added confidence rejection, temporal proximity scoring, a 65 mm maximum
  step, EMA output smoothing, and stale-track reset.
- Added Hough-circle recovery for a ball merged into a rail, wall, or blue
  handling tool.
- Added a recorder that saves frames, masks, per-frame measurements, manifests,
  and summaries.

### Camera-derived maze routes, 2026-08-10

`tools/plan_camera_maze.py` now treats the maze under the camera as the source
of truth. It uses the four-tag pose to rectify multiple frames into a 2 px/mm
top-down image, segments yellow rails and physically sized circular black
holes, then converts them to a 1 mm occupancy grid. Obstacles and the board
edge are inflated by the ball radius plus a configurable 0.5 mm safety margin before
clearance-weighted A* planning, line-of-sight pruning, and 5 mm waypoint
resampling.

The first live validation accepted 20/20 four-tag poses at 1.96 px median
reprojection, found all 13 visible holes, and generated a 275 mm route through
the current maze. The saved overlay and metric JSON are in
`artifacts/camera_maze/live_validation/`. This validates mapping and geometric
planning; following those waypoints with closed-loop ball control remains the
next layer.

### Actuator system identification

Built and completed on hardware 2026-08-06. `calib/servo_calibration.json` has
`measured=True`; `angle_to_counts` no longer raises.

The chain is: BNO086 IMU on an ESP32 streaming board tilt at 200 Hz, a sweep
tool that drives the servos and records settled angles, and a fit tool that
writes the contract only when the measurement supports the model it encodes.

#### Results

Calibrated from a conditioned sweep over ±1200 counts, centred on level.

| | roll (servo 1 → alpha) | pitch (servo 2 → beta) |
| --- | ---: | ---: |
| deg/count | 0.00487 | 0.00502 |
| counts_per_rad | 11776 | 11412 |
| centre (level) | 2215 | 2053 |
| calibrated range | 929–3329 | 902–3302 |
| span measured | 11.49° | 12.22° |
| linearity residual | 1.99% (0.229°) | 1.68% (0.205°) |
| **backlash, conditioned** | 0.031° | 0.140° |
| **backlash, unconditioned** | **1.06° mean, 1.42° max** | **0.94° mean, 1.54° max** |
| step latency | 185 ms | 150 ms |
| rise time (10–90%) | 256 ms | 230 ms |
| max rate | 6.9°/s | 8.2°/s |
| `max_tilt` | ±4.0° (headroom ±5.42°) | ±4.0° (headroom ±5.78°) |

A straight line holds across the **whole** working range: 12° of span at under
2% residual, better relative accuracy than the earlier ±320-count sweep managed
over 3°. The nonlinear `AxisCalibration` that seemed inevitable is not needed.

##### Backlash is the dominant error, and only one number is operational

| error source | magnitude |
| --- | ---: |
| IMU noise | 0.006° |
| command resolution (40 counts) | 0.19° |
| linear model residual | 0.23° |
| **backlash, unconditioned** | **~1.35°** |

Backlash is roughly **seven times everything else combined**. The conditioned
figures (0.031°/0.140°) describe what the mechanism can do when every approach
comes from the same side; the unconditioned ones describe what a controller that
reverses direction actually gets. **Use 1.35° for the simulator.** Putting the
conditioned number in would make a simulated roll axis forty times more precise
than the hardware.

The hysteresis is flat at 1.3–1.4° across the middle of the sweep and falls to
zero at both turnarounds, which is the signature of constant lost motion rather
than load-dependent compliance -- compliance would grow toward the extremes
where gravity torque is highest, and it does the opposite. So it models as a
reversal-triggered deadband, and needs no dependence on tilt angle.

It is also feedforward-correctable, and the constant is now measured: inject
about **277 counts on roll, 269 on pitch** at a direction reversal. With a ~100 ms
irreducible dead time capping any feedback loop at 0.2-0.3 Hz, that is the
highest-value control code for this rig.

#### Travel limits, 2026-08-06 (superseded by the renumbering below)

Stepping outward from level until the servo ran out of counts:

| | measured extremes | tilt span | safe range (300-count backoff) | safe span |
| --- | --- | ---: | --- | ---: |
| roll | 75 – 4025 | 18.06° | 371 – 3730 | 15.55° |
| pitch | 51 – 4088 | 20.96° | 347 – 3794 | 17.87° |

All four directions ended on the **servo's 0/4095 count limit**, not on a stall
or a gain collapse. That does not prove the plate was still free: the guard
cannot tell "resting against a stop" from "travelling" once the servo stops
being asked to move, so a 300-count backoff is applied on each side and recorded
in `calib/servo_travel_limits.json`.

Within the safe range:

| | usable about current level | best if level were centred |
| --- | ---: | ---: |
| roll | ±5.41° | **±7.77°** |
| pitch | ±8.12° | **±8.93°** |

**±10° is not reachable on either axis** inside the safe range. Roll caps at
±7.77° even perfectly centred, and would need roughly 29% more linkage ratio;
pitch needs about 12%. Level is currently 2.36° off-centre in roll's span and
0.81° in pitch's, so re-centring is worth more than any other single change.

These limits are deliberately **not** the same as `min_counts`/`max_counts` in
`servo_calibration.json`. Those are the range the linear fit was measured over
(±320 counts); these are the range it is safe to drive. Commanding angles across
the full safe range would extrapolate the fit roughly five times past its data.

#### Method: the two things that made it work

**Approach conditioning.** Every sweep point is reached from a fixed side, three
times, before the angle is read (`--condition-counts`, `--condition-cycles`).
Backlash fell from 0.734°/0.197° to 0.024°/0.040° — thirty-fold on roll — and
reproduced across two runs. Returning repeatedly to one count from a fixed side
settles to ±0.009° after about three cycles, against 0.73° when direction
varies. The lost motion is real but entirely deterministic; earlier sweeps
sampled both sides of it and read the difference as unreliability.

**Configuration pinned.** `STS3215Bus.CANONICAL_CONFIG` holds the motion
settings every measurement was taken under, with `apply_config` (write and
verify) and `check_config` (report drift). `ramp_to` no longer writes
`ACCELERATION` or `GOAL_SPEED` unless asked; it previously rewrote both on every
call, so any caller could invalidate the calibration silently.

`ACCELERATION = 50` is measured, not chosen: a 160-count step gave 270 ms of
board rise at the old value of 20 and 146 ms at 50, with 150 no better. Goal
speed was measured *not* to limit — rise time was flat across 100/200/500/1000.
**`GOAL_SPEED = 0` is not "maximum"** on this firmware; under it a 160-count step
moved the board 0.031° in 1.26 s, and `ramp_to` now rejects it.

#### What was ruled out

Servo 1 looked unreliable for most of the session — 0.73° of apparent backlash,
6.7% gain reproducibility against servo 2's 0.3%. Four explanations were tested
and failed, and recording them matters because each was believed at the time:

| Hypothesis | Test | Result |
| --- | --- | --- |
| Plate mechanically constrained | load guard aborts | guard was too strict, and the loads it tripped on were a decoding bug (see below) |
| Loose linkage | physical inspection | tight |
| Servo droop under load | encoder vs goal at P = 32/64/128 | lands on goal ±3 counts, zero load at rest; raising P changed nothing |
| IMU drift | 6-minute still log | 0.013° drift, 0.126° range — the sensor is good |

The answer was approach direction, above. Two corrections worth keeping:

- The load guard originally aborted on **load alone**, which rejected every
  upward move and read convincingly as a seized mechanism. A stall is high load
  **and no progress**; `ramp_to` now requires both, over several samples, and
  judges progress from an optional `motion_probe` (the IMU) rather than the
  encoder — servo 1 once advanced 200 counts through a dead zone while the plate
  moved 0.08°.
- Servo 1's travel limit was **numeric, not mechanical**. Level sat at count
  4093 of 4095, so the controller could not be handed a larger number.
  `calibrate_middle` (FEETECH's own middle-position calibration) renumbered both
  servos to 2048 with the board moving 0.0007°. An earlier version of this
  document recommended re-indexing the horn mechanically; that was wrong, and it
  was wrong because the mechanism was assumed rather than read — the servo's own
  limit registers said plainly the constraint was numeric.

#### Acceptance: why the linearity gate was changed

Both axes sit at 1.3–2.4% of span across runs, straddling the original 2% limit,
so pass/fail flipped between runs and between servos. Percentage-of-span is a
relative measure, and over a ~3° span it condemns errors nothing can act on:

| | model error | one 40-count command | share |
| --- | ---: | ---: | ---: |
| roll | 0.057° | 0.190° | 30% |
| pitch | 0.071° | 0.175° | 41% |

The linear model is finer than the smallest command this rig can issue — 40
counts, below which steps do not reliably keep their sign. `fit_sysid` now
accepts a residual under half of one commandable step, records the comparison in
its notes, and still blocks anything larger; two tests cover both directions.
`RATIO_MIN` was also widened from 0.05 to 0.01, because this rig's genuine ~20:1
reduction (ratio 0.050) tripped a guessed plausibility bound.

#### Limits to carry into the simulator

- **Gain depends on where it is measured.** Servo 2 read 0.00540 deg/count over
  ±400 counts, 0.00463 over ±320 centred at 2047, and 0.00437 over ±320 centred
  at 2018. The stored value is an average over the swept range and **must not be
  extrapolated past it**. The falloff is shared by both axes and is real
  geometry; a nonlinear mapping is the eventual right answer.
- **Action quantisation belongs in the model.** Commands under 20 counts do not
  reliably keep their sign; 40 counts (~0.19°) is the practical floor. A policy
  trained on continuous tilt will learn authority the hardware does not have.
- **Backlash is deterministic, not noise, and it dominates.** Model it as
  reversal-triggered lost motion, not as Gaussian error, and use the
  **unconditioned** figure of ~1.35° -- roughly seven times every other error
  source combined. The conditioned 0.031°/0.140° describes calibration
  conditions, not operation.
- **Dynamics are conditional on the pinned config.** Latency and rise time were
  measured at `ACCELERATION = 50`, `GOAL_SPEED = 500`, recorded in
  `servo_config`. A controller that changes them must re-measure.
- **~100 ms of the latency is electrical and irreducible**, which caps any
  feedback loop's bandwidth at roughly 0.2–0.3 Hz. Feedforward through the
  calibration plus reversal compensation is the right control shape here; a fast
  PID is not.

#### Range after renumbering, 2026-08-06

`calibrate_middle` renumbered both servos so level reads 2048, moving the count
wrap away from roll's travel. The board moved 0.003° -- nothing physical
changed, only the labels -- and roll's usable range improved:

| | before | after |
| --- | ---: | ---: |
| roll | ±5.40° | **±7.00°** |
| pitch | ±8.39° | ±8.36° |

Loads at every new extreme were 24-28, peak 40 anywhere, so the plate is not
contacting anything: the limit was purely the count wrap. That evidence was
unreadable before the load-decoding fix.

±10° is still out of reach. Roll would need roughly 30% more linkage ratio, and
the torque case for that is comfortable -- normal operation sits at 3-4% of
rated, so a faster linkage would reach perhaps 5%.

#### Feedforward tilt control, 2026-08-06

`tag_vision/control/tilt.py` maps a commanded board angle to servo counts with
the lost motion fed forward. Deliberately not a PID: ~100 ms of the latency is
electrical and irreducible, capping a stable feedback loop near 0.2-0.3 Hz,
while the two dominant errors -- the gain and the backlash -- are both
deterministic and both measured. An integrator would wind up inside the backlash
band and overshoot when the slack took up.

`STS3215Bus.sync_write_positions` sends both axes in one broadcast packet so
they latch together, closing the gap noted at the start of this work.

Measured on the rig by `tools/validate_backlash.py`, commanding
0/+2/0/-2 deg repeatedly:

| | compensation off | compensation on |
| --- | ---: | ---: |
| roll mean \|error\| | 0.876° | **0.261°** |
| pitch mean \|error\| | 0.427° | **0.258°** |
| spread at 0°, roll | 1.094° | **0.080°** |
| spread at 0°, pitch | 0.951° | **0.086°** |

##### The reference face matters more than the magnitude

The first implementation treated `center_counts` as the middle of the backlash
band and applied ±B/2. It is not: `sysid_actuator` conditions every point by
approaching from below, so the fit describes the **up branch**, the lower edge.
The correct inverse is asymmetric -- nothing travelling up, minus the full B
travelling down.

The wrong convention put every command half a backlash high, which showed up as
a +0.85° "centre bias" that survived compensation being switched on. With the
reference corrected it fell to +0.28°, and roll's positioning error improved
3.4×. `AxisBacklash.reference` now carries the convention explicitly, with a
test pinning all three.

##### Known second-order effects

- **Residual centre bias**, roll +0.28° and pitch −0.19°. This is genuinely the
  calibration centre, now comparable to the model residual rather than
  dominating it. A slow trim would remove it; this is the one place a small
  integral is safe, acting on a constant rather than on reversal dynamics.
- **Pitch's backlash is position-dependent** -- about 1.5° mid-range against
  0.4-0.6° near the extremes -- so a flat 1.211° overcorrects there, costing
  0.53° at −2°. Roll's is much flatter (1.19-1.42) and does not show it. A small
  table rather than a scalar would fix it.

#### Remaining

1. Fit position-dependent pitch backlash if dynamic validation shows the flat
   correction is inadequate near the operating extremes.
2. Fit nonlinear `AxisCalibration` if the current measured ±4° envelope needs
   more precision than the direction-dependent lookup provides.
3. Continue physical learned-control validation; the project intentionally
   prioritizes real data over the previously proposed MuJoCo path.

### Verification

- Added synthetic tests for angle convention, tag corner order and rotation,
  known-tag filtering, pose recovery, zeroing, blue-ball detection, coordinate
  recovery, distractor rejection, outside-board rejection, merged-component
  recovery, full-frame undistortion, and overlay projection consistency.
- Added synthetic tests for the IMU wire format (CRC rejection, resync after a
  dropped byte, sequence-gap counting, sequence wrap, stale-pong rejection) and
  for the sysid fits (gain/sign/centre recovery, backlash recovery, curvature
  showing up in the residual, latency and rise time from a first-order step,
  and the acceptance gate that decides `measured=True`).
- One real defect was found this way: with a step window shorter than the
  settling time, the final value came from a tail that was still moving, so the
  90% threshold was computed against a truncated delta and a confidently wrong,
  too-fast rise time was returned. `_step_metrics` now checks that the tail has
  settled and reports an error instead.
- Current result: **154 tests pass** across vision, IMU, actuator, planning,
  reset, replay, model, and RL-control components.
- A dry render on a real recorded frame placed the undistorted origin at about
  `(288.7, 691.7)` px, with finite +X/+Y endpoints inside the 1280 x 800 view.

## Recorded experiments

### Capture `20260804_172006`

- 335 frames.
- 0 accepted poses at the 4 px limit.
- 123 frames saw all four tags, but reprojection was about 10.83 px.
- Subset inspection isolated the mismatch to the bottom-right tag (ID 1), which
  was physically rotated relative to the configured geometry. The tag layout
  configuration was corrected/aligned before the next capture.

This recording is a useful example of why tag visibility alone is insufficient:
the reprojection gate correctly rejected a geometrically inconsistent solve.

### Capture `20260804_172347`

- 269 frames, recorded with three-tag poses permitted for diagnosis.
- 263 accepted poses (97.77%).
- Tag counts: 166 frames with all four; 94 with `(0,1,3)`; 3 with `(0,2,3)`;
  and 6 with no pose.
- Pose reprojection: 1.895 px median, 1.924 px 90th percentile, 1.963 px max.
- Four-tag static median: alpha 0.0623°, beta 0.8338° with standard deviations
  0.0134°/0.0072°.
- Common `(0,1,3)` median: alpha 0.5326°, beta 1.0298° with standard deviations
  0.0101°/0.0195°.
- The three-tag subset therefore shifted the result about +0.47° alpha and
  +0.20° beta. Four tags remain the production requirement.

The original contour-only detector reported only 10 detections because a blue
pair of scissors touched the marble and merged both objects into one component.
After adding edge-circle recovery, offline replay found a ball in 244 of 249
usable-pose frames (98.0% conditional recovery). Replay processing took about
33 ms/frame including image loading and pose estimation. At 10 Hz, the detected
trajectory had 3.4 mm median, 7.4 mm 90th-percentile, and 29.4 mm maximum
inter-sample movement.

These frames are not manually labeled, and the blue scissors are a major
distractor. The 98.0% number is a replay recovery rate, **not** a ground-truth
precision/recall measurement.

Raw captures remain locally under `artifacts/ball_capture/` and are excluded
from Git because they occupy about 136 MB. The recorder reproduces the same
directory structure.

## Current defaults

| Parameter | Default | Reason |
| --- | ---: | --- |
| Required tags | 4 | avoids observed three-tag angle bias |
| Max reprojection | 4.0 px | rejects inconsistent board geometry |
| Ball radius | 5.5 mm | physical marble radius |
| Ball confidence | 0.54 | tuned against current recordings |
| Ball EMA new-sample weight | 0.45 | reduces coordinate jitter |
| Track reset | after 3 misses | avoids displaying stale coordinates |
| Maximum temporal step | 65 mm | rejects remote blue distractors |

## Limitations and next work

1. Record a freely moving marble without scissors or other blue tools.
2. Label visible/not-visible frames and ball centres to measure precision,
   recall, false positives, coordinate error, jitter, and latency.
3. Cover the centre, rails, corners, shadows, motion blur, several tilt angles,
   and empty-board negative sequences.
4. Consider strict full-board acquisition followed by adaptive local tracking
   only if labeled results expose remaining misses.
5. Measure background colour statistics and seed-and-grow segmentation only if
   fixed thresholds fail under expected lighting variation.
6. Validate alpha/beta against known physical shims; reprojection residual is a
   self-consistency check, not proof of angle accuracy.
7. Re-measure nominal tag coordinates if absolute coordinate/angle errors are
   too large for control.
8. Add a fixed-frame tag or inertial/gravity reference if the camera must move
   without re-zeroing.
9. Continue measuring perception acceptance during physical policy training;
   maze representation and policy design are now implemented.

## Suggested perception acceptance criteria

Define these numerically before policy integration. A practical first target is:

- at least 99% four-tag pose availability in the intended operating envelope;
- no accepted poses above the 4 px reprojection gate;
- ball precision and recall each measured on labeled data rather than inferred
  from tracker continuity;
- coordinate error and jitter low enough relative to maze corridor clearance;
- processing latency comfortably below the future control-loop period;
- automatic `not visible` output during genuine occlusion instead of a guessed
  coordinate.

## 2026-08-10: camera maze planning and real model-based RL

The project now runs closed-loop learning on the physical maze. This work does
not use a simulator or sim-to-real transfer.

### Metric camera maze planning

`tools/plan_camera_maze.py` collects 20 four-tag poses, rectifies the board to
2 px/mm, forms a temporal median, detects yellow walls and circular black holes,
and plans in a 1 mm occupancy grid. Obstacles are inflated by the 5.5 mm marble
radius plus a configurable safety margin. Clearance-weighted A* is simplified
by line of sight and resampled at 5 mm. The accepted map under
`artifacts/camera_maze/20260810_125246` has a 623 mm route, 127 points, 13
detected holes, 62.0% occupied area after inflation, and 1.0 mm minimum extra
clearance. Generated artifacts remain ignored by Git.

### Camera and IMU fusion

The BNO086 moved to a separate Nano ESP32 so reload firmware and 200 Hz inertial
telemetry can operate concurrently. `CameraImuFusion` uses the IMU for fast
increments and valid four-tag camera poses for absolute correction. The level
references in `calib/board_zero.json` and `calib/imu_zero.json` were captured
together. The physical ±4° cross-check measured endpoint camera-vs-IMU RMSE of
0.145° alpha and 0.109° beta.

### Reset and reload behavior

The repeatable reload entry is handled deterministically rather than learned.
`calib/reload_brake.json` holds the measured backward tilt `[-0.77°, +1.35°]`.
After confirmed absence the controller holds that tilt, brakes the reappearing
marble, levels, and requires speed below 12 mm/s for 0.5 s before starting the
next episode. A detection gap first enters the cancellable
`CONFIRMING_DROP` state; reacquisition resumes the same episode. This prevents
a false loss from becoming a persistent `WAITING_FOR_DROP`. Brake timeout
levels safely and can recover when the marble subsequently stops or disappears
again.

### Real dynamics learning and control

The observation has 30 physical features: position, velocity, fused angles and
rates, previous action, route progress/cross-track/target/tangent, clearance,
stationary state, and 12 obstacle rays. Actions are two target angles. The
independent health shield enforces ±4°, 0.5° slew per 5 Hz step, fresh camera
and ball data, fusion agreement, servo communication, and load limits.

The continuous runner uses this lifecycle:

1. Start a fresh bounded replay and collect temporally coherent random targets,
   each held for 0.8 s.
2. Require at least 300 total and 120 moving transitions before first model
   activation.
3. Train five probabilistic PyTorch dynamics networks on the RTX 4070. Each
   bootstrap is balanced between moving and stationary transitions.
4. Atomically load completed checkpoints only between episodes and plan with
   CUDA CEM: 256 candidates, 10 steps, three iterations.
5. Run four learned-model episodes followed by one random exploration episode.
   A learned episode stationary for 3 s becomes `RECOVERY_EXPLORE`.
6. Snapshot and retrain every 100 additional transitions. Training runs in a
   child process during reload; `TRAINING_WAIT` keeps the board level if the
   reset finishes first.

Replay records the command actually executed after safety limiting, not the
unreachable proposal. Episode timeout is 60 s and continuous mode restarts at
the current detected position. Confirmed ball loss saves replay immediately;
normal exit also levels, releases torque, terminates background training, and
saves atomically.

The first online design activated after only 303 transitions. A representative
replay contained 464 stationary versus 68 moving transitions, and its model
predicted about 9 mm of forward progress over ten steps even at zero command.
CEM consequently selected median commands near 1.1° while all 909 observed CEM
samples remained stationary. This motivated the moving-data activation gate,
balanced bootstrap, reduction of the CEM effort coefficient from 0.008 to
0.0005, periodic random episodes, and stationary recovery. These are safeguards
against a deficient learned model, not a hard-coded breakaway angle.

### Camera throughput and resolution experiment

OpenCV now opens the See3CAM directly through V4L2 because the default
GStreamer backend rejected valid MJPEG negotiation. The verified device mode is
1920×1200 MJPEG at 60 FPS with a one-frame buffer. The sequential full pipeline
processes approximately 16–19 FPS. Ball-absent processing was accelerated 1.42×
by running board-wide Hough recovery every fifth frame; ordinary colour
reacquisition remains per-frame. Circle support is evaluated in local crops and
the maze distance transform is cached.

The experimental `--tag-detection calibrated` mode detects tags after uniform
resize to the existing 1280×800 calibration space. In a no-motor live A/B it
reduced median pose work from 3.22 to 2.08 ms and raised full-run processing
from 22.7 to 26.0 FPS, but accepted-pose rate fell from 33% in the already poor
current view to 0% at the 4 px reprojection gate. It is retained for diagnostics
but must not be used for execution. Native 1920×1200 detection remains the
production default. Native 1280×720 capture is 16:9 and requires a separate
intrinsic fit, camera zero, maze map, and coordinate validation; stretching it
to 1280×800 would invalidate geometry.

### Verification and current limitations

- `python3 -m pytest -q`: **154 passed**.
- Background trainer snapshot, checkpoint load, and CUDA inference handoff were
  exercised without motors.
- Replay and generated models live under ignored `artifacts/rl/runs/<stamp>`;
  they are deliberately not versioned.
- Current physical runs have not yet demonstrated a complete learned traversal.
  Progress must be evaluated as per-episode route gain, return, cross-track
  error, goal count, and recovery frequency. Neural validation RMSE alone is
  not an acceptance test.
- Do not mix 5 Hz and a future 8–10 Hz controller in one replay: the current
  observation does not include timestep, so transition duration is implicit.
- The current camera view must recover >80% four-tag pose availability before
  more hardware training; the last resolution A/B view was below this bar even
  at native resolution.

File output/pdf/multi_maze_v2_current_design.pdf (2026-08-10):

multi_maze_v2 - current design brief - 7 Aug 2026 | Page 1

# multi_maze_v2

## Current control, simulation, and learning design

Goal: learn a reliable ball-maze policy from measured physics and model-predictive demonstrations, then adapt safely to real hardware.

Server demonstration generation | 4,825 / 5,000 safely saved
96.5% complete | 4 active CPU workers - 0 errors

# System at a glance

Evidence already established | Result
Representative MPC canary | 75/75 goals; 0 falls; 0 timeouts
Geometry coverage | Authentic, mirrored-authentic, and procedural
Robustness coverage | Sensor noise and physics randomization up to 25%
Local episode policy | Completion first; 60 s maximum budget
Server execution | 20 disjoint workers; resumable 25-episode shards

Design principle: known mechanics supply structure; learning is used for flexible route following, recovery, and the remaining sim-to-real gap.

# 1. Current MPC teacher design

The teacher replans at 20 Hz. It predicts candidate action sequences with an analytical rolling-ball and measured actuator surrogate, then executes only the first action in MuJoCo before planning again.

Estimated state
position + velocity

Analytical prior
pure-pursuit controller

CEM search
192 candidates
30 steps

MuJoCo step
contacts are authoritative

Replan
closed-loop correction

## Teacher parameters

Element | Current setting | Reason
Planning horizon | 30 control steps / 1.5 s | Anticipates momentum and braking
CEM population | 192 candidates, 4 iterations, 24 elites | Broad search with bounded runtime
Analytical prior | Pure-pursuit velocity field | Known-safe feedback anchor
MPC residual | +/- 0.03 normalized action | Prevents model-error wall stalls
Execution plant | MuJoCo | Retains real contacts, walls, and holes
Local timeout | 60 s | Allows robust completion under randomization

## Why the teacher is hybrid

Known physics contributes | MuJoCo contributes | Learning later contributes
Gravity-driven ball acceleration; actuator dead time, lag, slew, and backlash; route geometry and stopping logic. | Wall and floor contacts; hole falls; exact maze geometry; authoritative next state. | One compact policy; recovery from unfamiliar states; residual compensation on the real rig.

Safety correction discovered by the canary: a 12% MPC residual degraded one mirrored sharp-right geometry. Reducing it to 3% and restoring the 60 s completion budget produced 75/75 representative successes.

# 2. Ball-on-plate mathematical model

This model lives inside the MPC prediction loop. For every candidate plate-command sequence, it predicts the ball trajectory cheaply; MuJoCo then executes the selected first action and supplies the authoritative contact-rich next state.

Action sequence
normalized commands

Actuator model
delay + lag + slew

Plate angles
alpha + beta

Ball equations
acceleration + damping

Predicted path
position + velocity

## Rolling-sphere dynamics

x-axis motion

x'' = (5/7) g sin(beta) - c x'

y-axis motion

y'' = -(5/7) g sin(alpha) - c y'

Rolling gain: (5/7) g = 7.007 m/s^2 per radian for small tilts

The 5/7 factor follows from a solid sphere rolling without slipping: part of gravity accelerates translation and part accelerates rotation. The fitted linear term c opposes velocity and approximates rolling resistance plus residual simulator damping.

## Variables and sign convention

Symbol | Meaning | Project convention
alpha | Plate roll angle | Positive alpha accelerates the ball toward negative y
beta | Plate pitch angle | Positive beta accelerates the ball toward positive x
g | Gravity | 9.81 m/s^2
c | Linear damping coefficient | ball.linear_damping from parameters.json
x', y' | Board-frame ball velocity | Estimated and latency-predicted state

## Closed-form control-step integration

Update | Equation
Position | p_next = p + v dt + 0.5 a dt^2
Velocity | v_next = v + a dt

## Implementation and limits

- sim/analytic_model.py contains the scalar equations, rollout, stopping-time, and switching-curve helpers.
- control/mpc_teacher.py applies the same equations to 192 candidate sequences in parallel.
- The predictor includes measured actuator dead time, first-order lag, slew limits, and backlash before the ball equations.

# 3. Balanced local-skill curriculum

The teacher demonstrates short maneuvers separately. Balanced sampling prevents abundant straight motion from dominating rare turns.

Maneuver | Geometries | Initial conditions | Episode target
Straight | 50 | 20 per geometry | 1,000
Gentle left | 50 | 20 per geometry | 1,000
Gentle right | 50 | 20 per geometry | 1,000
Sharp left | 50 | 20 per geometry | 1,000
Sharp right | 50 | 20 per geometry | 1,000
Total | 250 | 5,000 specifications | 5,000

## Geometry sources

Source | Count | Purpose
Authentic | 42 | Local slices of the actual maze
Mirrored authentic | 42 | Valid reflected layouts with walls and holes reflected too
Procedural | 166 | Fills class imbalance and expands shape diversity

## Initial-condition coverage

- Lateral offsets span both sides of the route centerline within local clearance.
- Forward and lateral velocities vary so the teacher demonstrates braking and recovery, not only rest starts.
- Physics randomization levels include nominal, 10%, and 25%, with sensor noise enabled.

# Representative teacher demonstrations

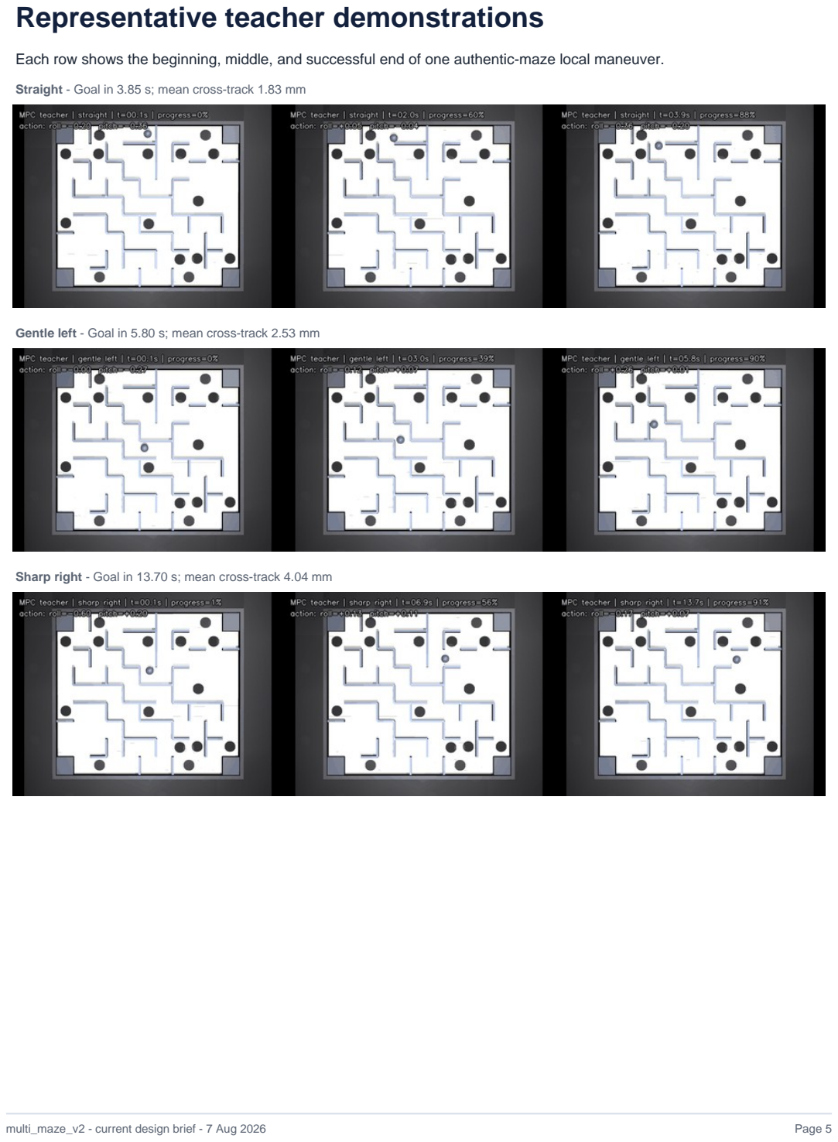
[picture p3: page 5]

Each row shows the beginning, middle, and successful end of one authentic-maze local maneuver.

Straight - Goal in 3.85 s; mean cross-track 1.83 mm

Gentle left - Goal in 5.80 s; mean cross-track 2.53 mm

Sharp right - Goal in 13.70 s; mean cross-track 4.04 mm

# 4. One route-conditioned imitation policy

The short skills are not deployed as five separate controllers. Their successful transitions are pooled to train one policy that selects the appropriate behavior from the local route shape.

### 5 skill datasets

balanced examples

22-float observation
state + route lookahead

Neural policy
shared representation

2-float action
roll + pitch command

Complete route
skills blend continuously

## Policy contract

Observation block | Floats | Meaning
Ball position | 2 | Board-normalized x and y
Predicted ball velocity | 2 | Latency-compensated vx and vy
Board angles | 2 | Normalized roll and pitch
Action history | 6 | Three previous two-axis commands
Route lookahead | 10 | Five ball-relative points at 12 mm spacing
Total | 22 | State-based, route-conditioned observation

## Behavior-cloning objective

For every saved teacher transition, minimize the squared difference between the policy action and the MPC action: L = mean || policy(observation) - teacher_action ||^2.

## Training split and balancing

- Split by complete geometry, never by individual frame, so validation routes are genuinely unseen.
- Balance maneuver classes and emphasize recovery states instead of letting long straight trajectories dominate.
- Train on the server GPU, but judge models through closed-loop simulation rather than action loss alone.
- Save the best checkpoint by evaluation success, not merely the final epoch.

The route-conditioned policy does not explicitly choose 'turn left' or 'go straight.' Five relative lookahead points describe the local shape, and the shared network produces the matching action continuously.

# 5. Closed-loop evaluation and recovery

Low imitation loss is necessary but not sufficient. Small action errors can move the ball into states absent from the teacher data, so every candidate policy must be executed in simulation.

Train policy
behavior cloning

Run closed loop
held-out segments

Collect failures
drift + recovery states

MPC relabels
correct action

Retrain
expanded dataset

## Evaluation ladder

Gate | Primary measures | Decision
Held-out local segments | Success by class; falls; completion; cross-track | Target >=95% success with near-zero falls
Unseen procedural routes | Generalization across radius, angle, and placement | Reject memorized geometry
Full nominal maze | Start-to-goal success and accumulated drift | Prove that local skills compose
Randomized simulation | Success under friction, latency, bias, and noise | Measure robustness before hardware
Hardware canary | Conservative speed, tilt, and emergency-stop behavior | Expand only after safe repeatability

## Anti-collapse protections for later SAC fine-tuning

- Retain teacher demonstrations in replay rather than replacing them with weak on-policy behavior.
- Use an imitation regularizer so the actor cannot drift rapidly away from the successful teacher manifold.
- Use a small learning rate, periodic deterministic evaluation, and best-checkpoint protection.
- Stop or roll back when success falls, even if TensorBoard training reward rises.

Success is always an executed outcome. Route completion alone does not prove that the ball reached the goal, and training reward alone does not prove that the policy is stable.

# 6. Execution roadmap

## Current server layout

Item | Current design
Remote project | /home/tn22833/multi_maze_v2
Teacher generation | 20 disjoint CPU workers; 25 episodes per resumable shard
Hardware available | 256 CPU cores; five RTX 6000 Ada GPUs with 49 GB each
Current status snapshot | 4,825/5,000 saved; 4 workers active; 0 error logs
Next runtime | GPU-enabled PyTorch for behavior cloning and later SAC

## Milestones from here

Stage | Work | Exit condition
A. Corpus closeout | Verify 5,000 episodes, unique IDs, readable shards, class/source balance | Integrity report passes
B. Behavior cloning | Train one route-conditioned policy on GPU | Validation loss stable; no train/validation leakage
C. Segment evaluation | Run held-out authentic, mirrored, and procedural routes | >=95% local success; near-zero falls
D. DAgger recovery | MPC relabels states reached by policy drift | Recovery failures materially reduced
E. Full-maze evaluation | Nominal and randomized start-to-goal runs | Reliable goal success, not completion only
F. Protected RL | Fine-tune with SAC plus demonstration retention | Beats imitation without checkpoint collapse
G. Hardware transfer | Conservative canary, system identification, residual adaptation | Safe repeatable real-maze runs

## Final architecture

The intended result is not an MPC controller running permanently on the robot. MPC supplies high-quality behavior offline; the learned route-conditioned policy supplies fast online control; hardware data then corrects the remaining model mismatch.

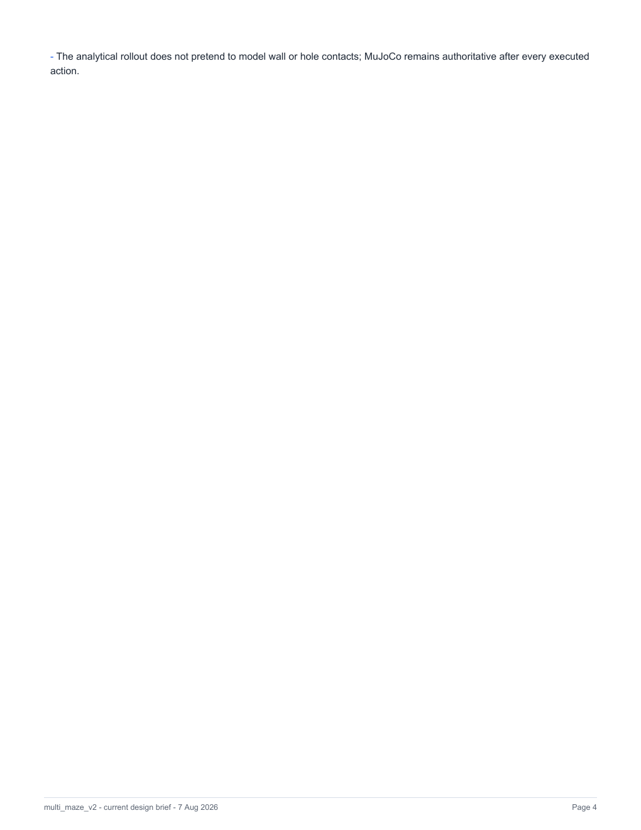
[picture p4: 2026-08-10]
tmp/pdfs/rendered/design-v3-4.png

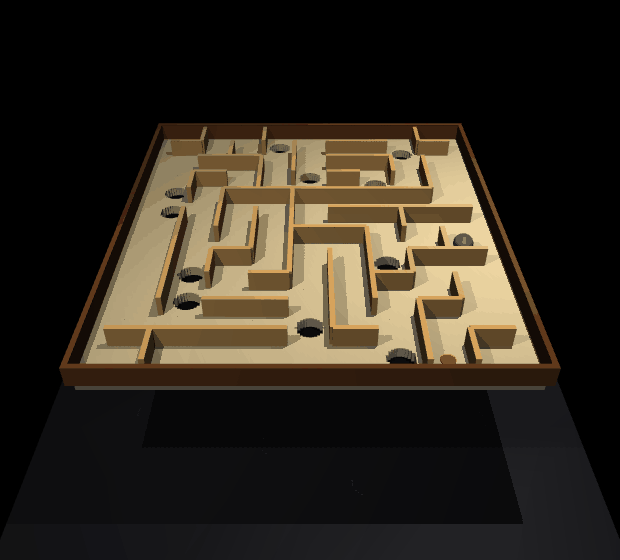
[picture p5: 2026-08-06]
maze_design/maze_v1_orbit.gif

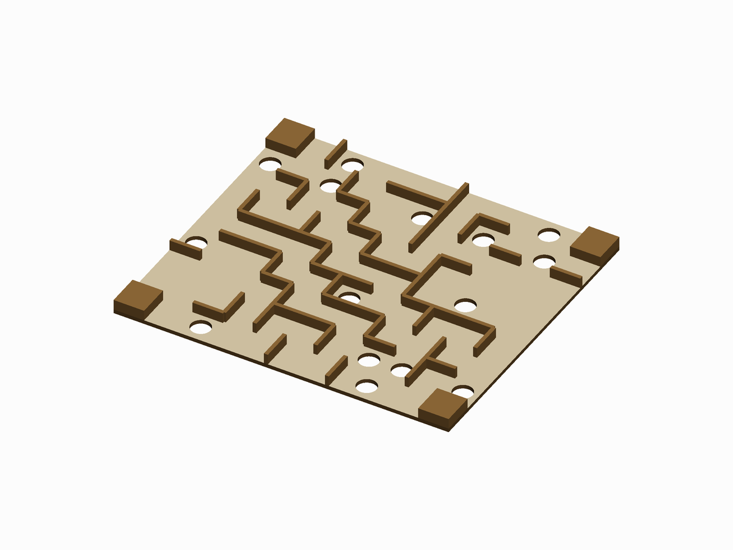
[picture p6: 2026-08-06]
maze_design/maze_256x226_3d.png

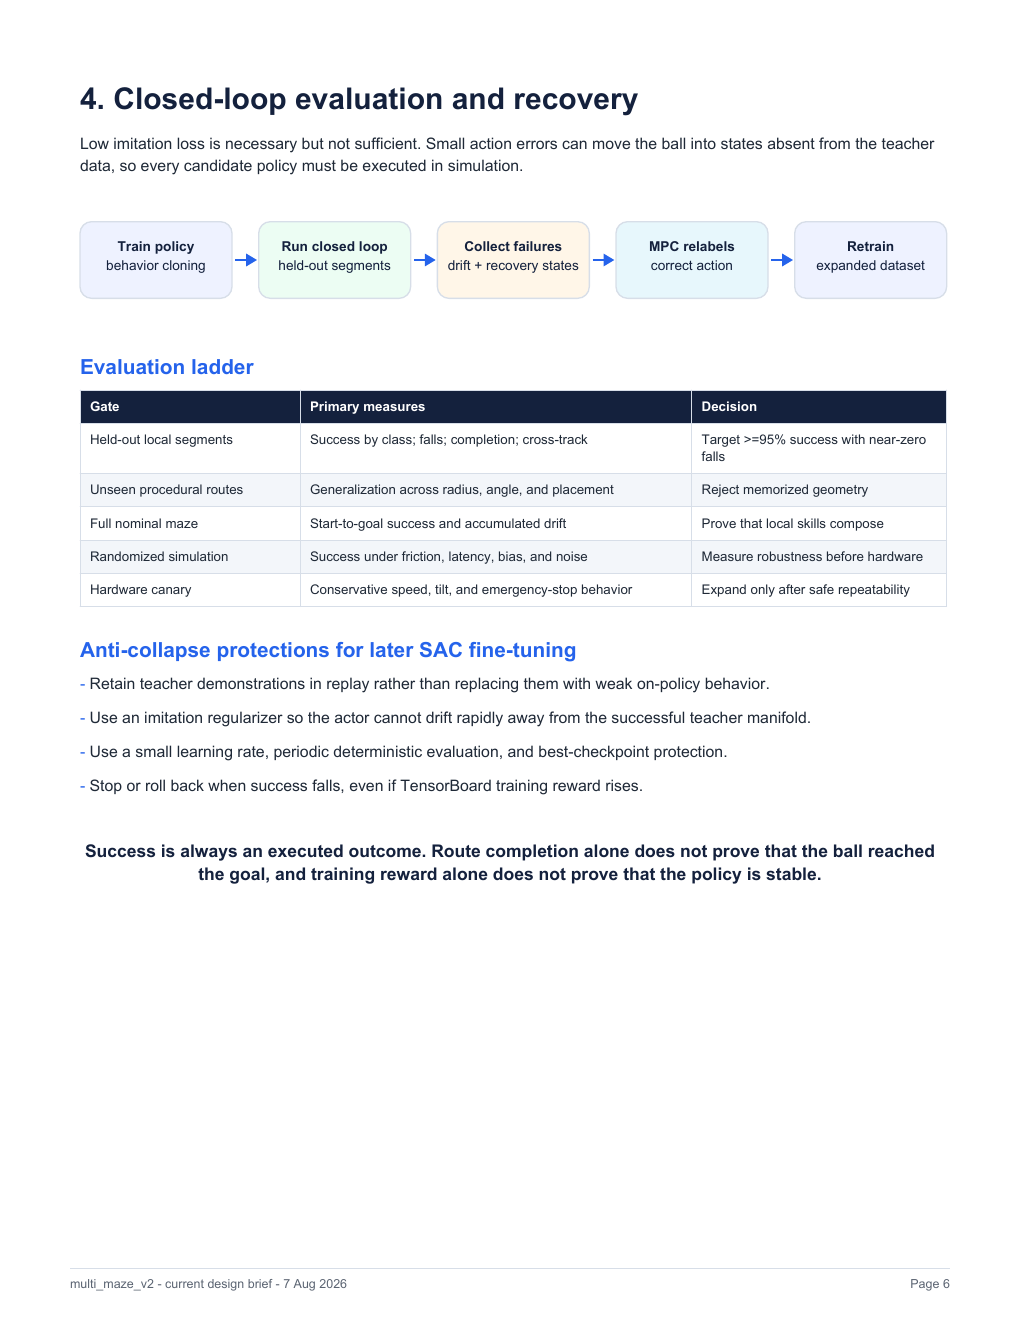
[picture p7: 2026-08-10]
tmp/pdfs/rendered/design-6.png

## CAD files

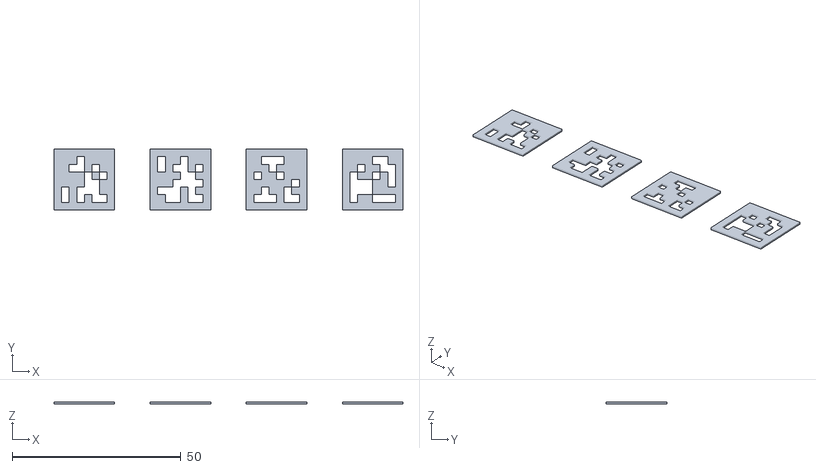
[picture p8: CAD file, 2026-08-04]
calib/corner_tags_18mm_black.stl
103.5 x 18.0 x 0.6

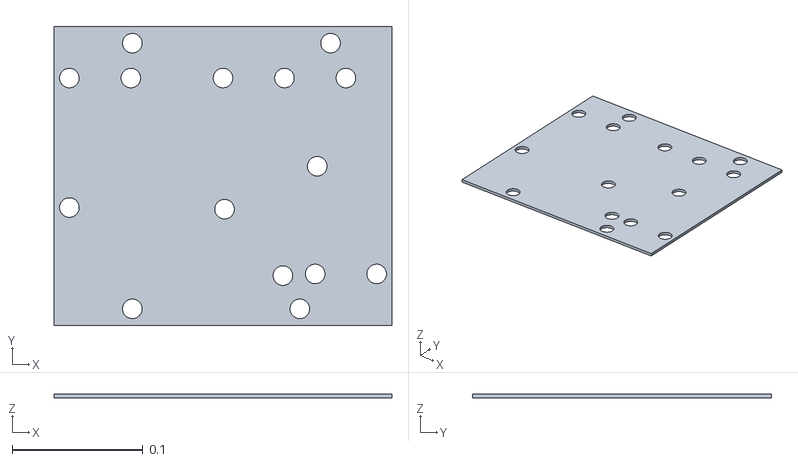
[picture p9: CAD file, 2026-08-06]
maze_design/maze_print_floor.stl
0.259 x 0.229 x 0.003

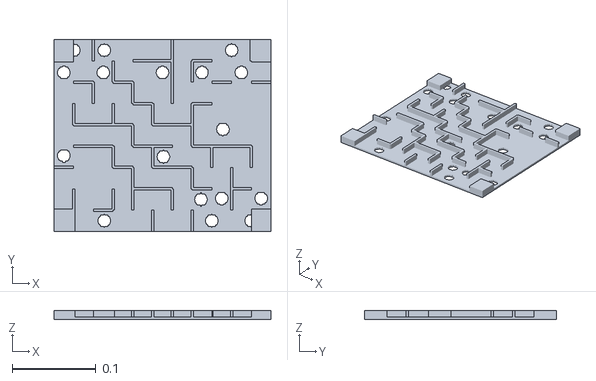
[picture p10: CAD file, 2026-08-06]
maze_design/print/maze_final/maze_prototype_binary.stl
0.259 x 0.229 x 0.011

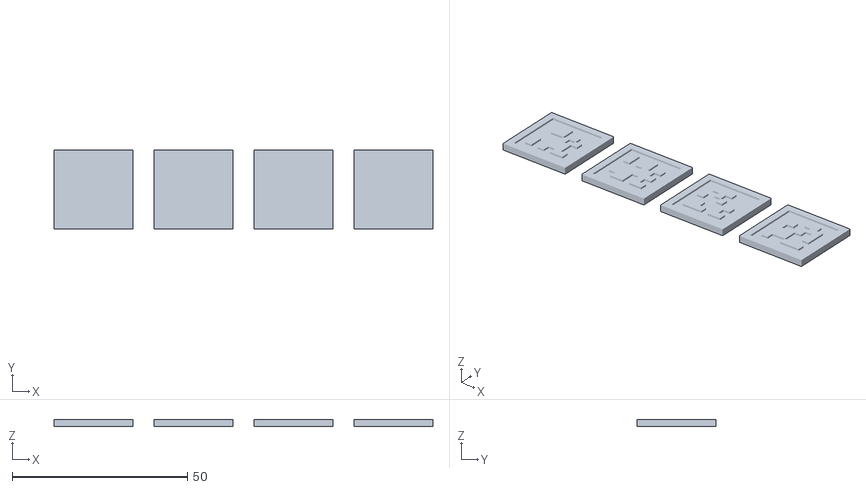
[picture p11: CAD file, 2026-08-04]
calib/corner_tags_18mm_white.stl
108.0 x 22.5 x 2.10

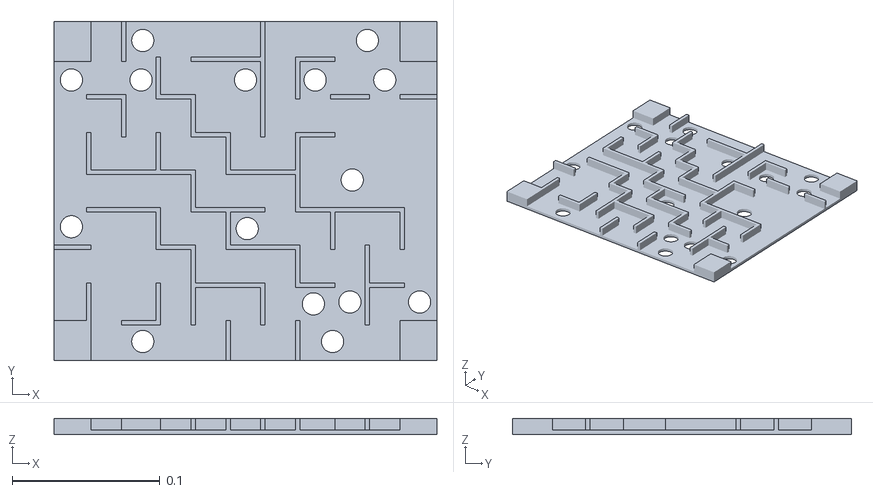
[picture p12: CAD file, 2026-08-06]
maze_design/maze_print.stl
0.259 x 0.229 x 0.011

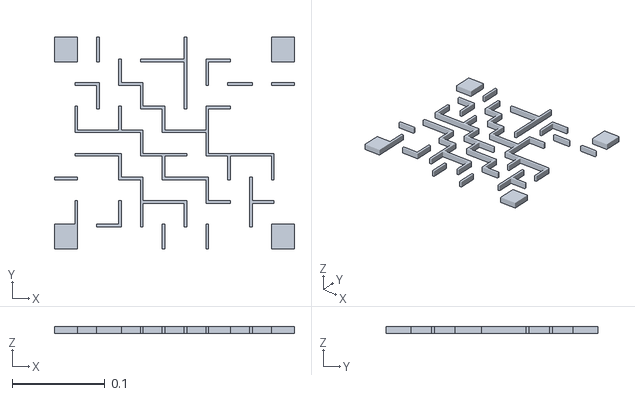
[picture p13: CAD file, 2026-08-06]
maze_design/maze_print_walls.stl
0.259 x 0.229 x 0.008

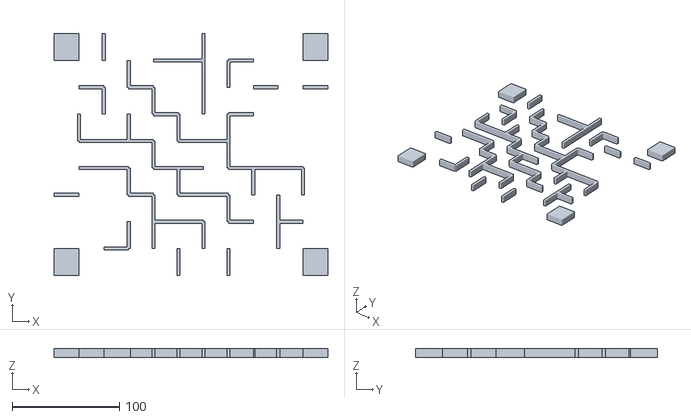
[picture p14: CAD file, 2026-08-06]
maze_design/maze_256x226_walls.stl
256.0 x 226.0 x 8.00

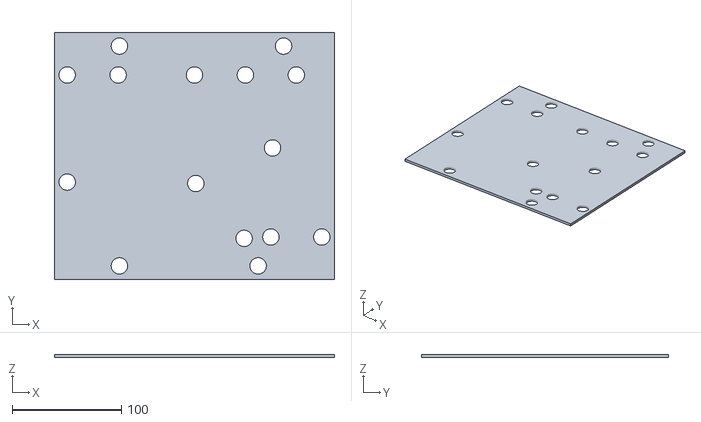
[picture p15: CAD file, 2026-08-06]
maze_design/maze_256x226_floor.stl
256.0 x 226.0 x 3.00

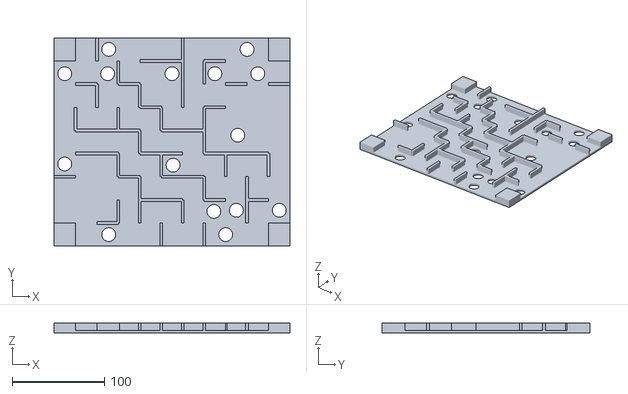
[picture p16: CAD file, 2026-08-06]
maze_design/maze_256x226.stl
256.0 x 226.0 x 11.0

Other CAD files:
maze_design/print/maze_final/maze_prototype.stl

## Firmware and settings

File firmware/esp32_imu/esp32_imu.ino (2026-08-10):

// Stream BNO086 board tilt to the host as compact binary frames.
//
// Why binary rather than CSV. The USB-serial link on this rig is not reliable
// above 115200: flash reads at 921600 and 460800 both stalled at exactly
// 0x6000, and one 512 KB chunk needed a retry even at 115200. So the baud is
// fixed at 115200 and the frame has to fit inside it. A CSV line of quaternion
// floats runs ~60 bytes; at 200 Hz that is 12 kB/s against roughly 11.5 kB/s of
// usable bandwidth -- over budget, and the failure mode is silent backpressure
// that shows up as jitter in exactly the latency numbers sysid is measuring.
// The 17-byte frame below is 3.4 kB/s at 200 Hz.
//
// Why GAME rotation vector rather than the fused one. Game rotation vector is
// gravity-referenced but ignores the magnetometer. Two STS3215 servos drawing
// current a few centimetres away disturb any magnetometer-fused heading, and
// tilt is the one thing here that must stay clean. Yaw drift does not matter:
// the board's alpha/beta come from gravity alone.
//
// Quaternions are sent as Q14 fixed point, which is the BNO's own native
// scaling -- the library hands out floats it converted from Q14, so this
// converts back rather than introducing a new quantisation.

#include <Wire.h>
#include "SparkFun_BNO08x_Arduino_Library.h"

// ---- wiring ---------------------------------------------------------------
// SparkFun Qwiic: red 3V3, black GND, blue SDA, yellow SCL.
//
// Use the board variant's named I2C pins. On Arduino Nano ESP32 these are
// A4/SDA and A5/SCL. Using SDA/SCL rather than raw ESP32 GPIO numbers also
// works with either of the Nano core's Arduino-pin or GPIO-pin numbering modes.
static const int PIN_SDA = SDA;
static const int PIN_SCL = SCL;
// BNO086 clock stretching is timing-sensitive on the Nano ESP32's ESP32-S3.
// Use standard mode for a reliable SH-2 startup; 100 kHz is still ample for
// the compact 200 Hz game-rotation-vector report.
static const uint32_t I2C_HZ = 100000;

static const uint32_t SERIAL_BAUD = 115200;

// MILLISECONDS, not microseconds. enableGameRotationVector takes a uint16_t and
// multiplies it by 1000 internally (library .cpp line 840), so passing 5000
// here would ask for one report every five seconds rather than 200 Hz -- a
// mistake that produces a working stream at 1/1000th the intended rate, which
// is exactly the kind that survives a bring-up check and ruins the dynamics.
static const uint16_t REPORT_INTERVAL_MS = 5;  // 200 Hz

// ---- framing --------------------------------------------------------------
// [0xA5][0x5A][type][len][payload...][crc8]
// crc8 covers type, len, and payload -- not the sync word, which is what the
// host uses to resynchronise after a dropped byte.
static const uint8_t SYNC0 = 0xA5;
static const uint8_t SYNC1 = 0x5A;

static const uint8_t TYPE_SAMPLE = 0x01;  // 12 bytes: u32 micros, 4x i16 quat, u8 acc, u8 seq
static const uint8_t TYPE_PONG   = 0x02;  // 8 bytes:  u32 token, u32 esp micros
static const uint8_t TYPE_STATUS = 0x03;  // ASCII, for bring-up messages

BNO08x imu;
static bool imu_ok = false;

// Frame counter, incremented per transmitted sample and wrapping at 256.
//
// Note what this does and does not catch. It is generated here, not taken from
// the SH-2 report header, so it detects frames lost between this device and the
// host -- serial overrun, a dropped byte resyncing the parser -- which is the
// failure this link is actually prone to. It does not detect a report the BNO
// itself skipped. Those show up instead as a gap in the micros timestamp, which
// is why the timestamp is sent per sample rather than assumed from the rate.
static uint8_t seq = 0;

// Recovery pacing for a sensor that failed to start.
static const uint32_t RETRY_INTERVAL_MS = 2000;
static uint32_t last_retry_ms = 0;

// Dallas/Maxim CRC-8 (poly 0x31). Small enough to be worth having: a corrupt
// quaternion that still parses would look like a real board movement.
static uint8_t crc8(const uint8_t *data, size_t len) {
  uint8_t crc = 0x00;
  for (size_t i = 0; i < len; i++) {
    crc ^= data[i];
    for (uint8_t b = 0; b < 8; b++) {
      crc = (crc & 0x80) ? (uint8_t)((crc << 1) ^ 0x31) : (uint8_t)(crc << 1);
    }
  }
  return crc;
}

static void sendFrame(uint8_t type, const uint8_t *payload, uint8_t len) {
  uint8_t header[2] = {type, len};
  uint8_t crc = crc8(header, 2);
  // Continue the CRC across the payload without copying it into a buffer.
  for (uint8_t i = 0; i < len; i++) {
    uint8_t byte = payload[i];
    crc ^= byte;
    for (uint8_t b = 0; b < 8; b++) {
      crc = (crc & 0x80) ? (uint8_t)((crc << 1) ^ 0x31) : (uint8_t)(crc << 1);
    }
  }
  Serial.write(SYNC0);
  Serial.write(SYNC1);
  Serial.write(type);
  Serial.write(len);
  Serial.write(payload, len);
  Serial.write(crc);
}

static void sendStatus(const char *msg) {
  size_t n = strlen(msg);
  if (n > 200) n = 200;
  sendFrame(TYPE_STATUS, (const uint8_t *)msg, (uint8_t)n);
}

static void put_u32(uint8_t *dst, uint32_t v) {
  dst[0] = (uint8_t)(v);          dst[1] = (uint8_t)(v >> 8);
  dst[2] = (uint8_t)(v >> 16);    dst[3] = (uint8_t)(v >> 24);
}

static void put_i16(uint8_t *dst, int16_t v) {
  dst[0] = (uint8_t)(v);          dst[1] = (uint8_t)(v >> 8);
}

// Float quaternion component -> Q14, saturating. A unit quaternion component
// is within [-1, 1], so 16384 is the natural scale and saturation should never
// fire; if it does, something upstream is wrong and clipping is better than
// wrapping to the opposite sign.
static int16_t to_q14(float v) {
  long scaled = lroundf(v * 16384.0f);
  if (scaled >  32767) scaled =  32767;
  if (scaled < -32768) scaled = -32768;
  return (int16_t)scaled;
}

static bool enableReports() {
  return imu.enableGameRotationVector(REPORT_INTERVAL_MS);
}

// Free a bus that a device is holding low.
//
// The BNO086 has its own supply and no reset line wired here, so resetting the
// ESP32 does not reset the sensor. If it is stuck partway through a transaction
// it keeps SDA low, and every subsequent begin() fails while the device still
// ACKs its address -- which is exactly what happened after the rig was
// unplugged and reconnected: an I2C scan found 0x4B present, yet begin() would
// not complete. Clocking SCL lets the device finish the byte it was in.
static void recoverBus() {
  pinMode(PIN_SDA, INPUT_PULLUP);
  pinMode(PIN_SCL, OUTPUT);
  for (int i = 0; i < 9 && digitalRead(PIN_SDA) == LOW; i++) {
    digitalWrite(PIN_SCL, LOW);  delayMicroseconds(5);
    digitalWrite(PIN_SCL, HIGH); delayMicroseconds(5);
  }
  digitalWrite(PIN_SCL, HIGH);
}

// Try to bring the sensor up. Safe to call repeatedly.
static bool tryBegin() {
  recoverBus();
  if (!Wire.begin(PIN_SDA, PIN_SCL, I2C_HZ)) {
    sendStatus("Wire.begin failed on labeled SDA/SCL pins");
    return false;
  }
  Wire.setTimeOut(50);
  delay(50);
  uint8_t address = 0;
  for (uint8_t candidate : {0x4B, 0x4A}) {
    Wire.beginTransmission(candidate);
    if (Wire.endTransmission() == 0) {
      address = candidate;
      break;
    }
  }
  if (address == 0) {
    sendStatus("no I2C response at BNO086 address 0x4B or 0x4A");
    return false;
  }
  sendStatus(address == 0x4B ? "I2C ACK at 0x4B; starting BNO086"
                             : "I2C ACK at 0x4A; starting BNO086");
  if (!imu.begin(address, Wire)) return false;
  return enableReports();
}

void setup() {
  Serial.begin(SERIAL_BAUD);
  // Nano ESP32 uses native USB CDC. Give the host monitor time to open so the
  // one-shot startup diagnostics are not discarded before a reader exists.
  uint32_t usb_wait_started = millis();
  while (!Serial && millis() - usb_wait_started < 10000) delay(10);
  sendStatus("Nano ESP32 IMU firmware started");

  // Two addresses exist in the wild: 0x4B is the SparkFun default, 0x4A is the
  // ADR-jumper alternative. tryBegin attempts both after recovering the bus.
  imu_ok = tryBegin();
  sendStatus(imu_ok ? "BNO086 ready: game rotation vector @ 200 Hz"
                    : "BNO08x did not start; will keep retrying. If it never "
                      "comes up, check 3V3/GND and the board's labeled "
                      "SDA/SCL pins.");
}

void loop() {
  // Host commands. 'P' + 4-byte token -> PONG, so the host can measure link
  // round-trip and de-bias step_latency_s. Without this, every latency number
  // silently includes an unknown amount of USB-serial transport delay.
  if (Serial.available() >= 1) {
    int cmd = Serial.read();
    if (cmd == 'P') {
      uint8_t token[4];
      size_t got = Serial.readBytes(token, 4);
      if (got == 4) {
        uint8_t payload[8];
        memcpy(payload, token, 4);
        put_u32(payload + 4, micros());
        sendFrame(TYPE_PONG, payload, 8);
      }
    } else if (cmd == 'R') {
      // Re-enable reports without a power cycle: the BNO stops reporting after
      // certain resets, and this recovers it without disturbing the rig. The
      // board must not be bumped while the level zero is in force.
      if (imu_ok) sendStatus(enableReports() ? "reports re-enabled"
                                             : "re-enable failed");
    }
  }

  // Retry rather than giving up for the lifetime of the boot. The sensor can
  // be left latched by a replug, and since resetting the ESP32 does not reset
  // it, a one-shot begin() in setup() would strand the stream permanently --
  // which is what it did.
  if (!imu_ok) {
    if (millis() - last_retry_ms >= RETRY_INTERVAL_MS) {
      last_retry_ms = millis();
      imu_ok = tryBegin();
      sendStatus(imu_ok ? "BNO086 recovered"
                        : "BNO08x still unavailable, retrying");
    }
    delay(20);
    return;
  }

  if (imu.wasReset()) {
    // A reset silently drops the report subscription. Saying so matters: the
    // alternative is a host that sees the stream stop and cannot tell whether
    // the board is still or the sensor is gone.
    sendStatus("BNO08x reset detected, re-enabling reports");
    enableReports();
  }

  if (imu.getSensorEvent()) {
    if (imu.getSensorEventID() == SENSOR_REPORTID_GAME_ROTATION_VECTOR) {
      uint8_t payload[12];
      put_u32(payload + 0, micros());
      put_i16(payload + 4, to_q14(imu.getGameQuatI()));
      put_i16(payload + 6, to_q14(imu.getGameQuatJ()));
      put_i16(payload + 8, to_q14(imu.getGameQuatK()));
      put_i16(payload + 10, to_q14(imu.getGameQuatReal()));
      // Payload is 12 bytes of quaternion + timestamp; accuracy and sequence
      // ride in the two trailing bytes below.
      uint8_t full[14];
      memcpy(full, payload, 12);
      // getQuatAccuracy, not getGameQuatAccuracy -- the latter does not exist.
      // The library keeps one shared quatAccuracy field for both the fused and
      // game rotation vectors.
      full[12] = (uint8_t)imu.getQuatAccuracy();
      full[13] = seq++;
      sendFrame(TYPE_SAMPLE, full, 14);
    }
  }
}

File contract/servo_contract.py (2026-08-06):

"""Actuator contract for the FEETECH STS3215 tilt servos.

Three layers, so hardware units never leak into the policy:

    policy action [-1, 1]  ->  desired board angle (rad)  ->  servo counts
            contract                    contract                 driver

The middle representation is physical, which is the point. The previous contract
mapped policy output straight onto a servo's native units (``servo_home=500``,
``servo_limits=(100, 900)``), so it silently described a 0-1000 device and became
wrong the moment the motor changed. Board angle is a property of the machine, not
of whatever servo happens to be bolted to it.

The angle -> counts mapping is **measured**, never assumed. A nominal STS3215 has
4096 counts over 2*pi rad (about 651.9 counts/rad), but that only equals the board
mapping if the servo drives the plate 1:1, which no real linkage does. Gain,
offset, and sign all come from the static sweep in ``tools/sysid_actuator.py``.

Until those measurements exist, ``AxisCalibration.measured`` is False and any
attempt to convert an angle to counts raises. Bring-up deliberately bypasses this
by commanding raw counts through the driver: you cannot calibrate the mapping
using the mapping.

These numbers describe **position mode** (``Register.MODE == 0``) with the servo's
own PID as recorded at measurement time. Switching to PWM mode, or retuning the
internal gains, invalidates them -- hence ``servo_config`` on the contract.
"""
from __future__ import annotations

import json
import math
from dataclasses import asdict, dataclass, field
from pathlib import Path

CONTRACT_VERSION = "tag_sts3215_servo_v1"

# Nominal STS3215 scaling, for sanity-checking a measured fit -- not for use.
NOMINAL_COUNTS_PER_REV = 4096
NOMINAL_COUNTS_PER_RAD = NOMINAL_COUNTS_PER_REV / (2.0 * math.pi)


class CalibrationError(RuntimeError):
    """Raised when an unmeasured or out-of-range calibration is used."""


@dataclass(frozen=True)
class AxisCalibration:
    """Measured mapping from board angle to servo counts for one axis.

    counts = center_counts + sign * counts_per_rad * angle_rad
    """

    servo_id: int
    counts_per_rad: float = NOMINAL_COUNTS_PER_RAD
    center_counts: int = 2048
    sign: int = 1

    # Hard travel limits in counts. Commands are clamped to these regardless of
    # what the angle limit permits, so a bad gain cannot drive into a hard stop.
    min_counts: int = 0
    max_counts: int = 4095

    # Measured, informational: consumed by the simulator, not by the mapping.
    deadband_counts: float | None = None
    backlash_rad: float | None = None
    step_latency_s: float | None = None
    rise_time_s: float | None = None
    max_rate_rad_s: float | None = None

    measured: bool = False

    def __post_init__(self) -> None:
        if self.sign not in (1, -1):
            raise ValueError(f"sign must be +1 or -1, got {self.sign}")
        if self.counts_per_rad <= 0:
            raise ValueError("counts_per_rad must be positive; encode direction in sign")
        if not self.min_counts <= self.center_counts <= self.max_counts:
            raise ValueError(
                f"center_counts {self.center_counts} outside travel limits "
                f"{self.min_counts}..{self.max_counts}"
            )

    def angle_to_counts(self, angle_rad: float) -> int:
        """Convert a board angle to a servo count, clamped to travel limits."""
        if not self.measured:
            raise CalibrationError(
                f"axis on servo {self.servo_id} is not calibrated. Run "
                "tools/sysid_actuator.py to measure gain, offset, and sign. "
                "Bring-up should command raw counts through the driver instead."
            )
        raw = self.center_counts + self.sign * self.counts_per_rad * float(angle_rad)
        return int(round(min(max(raw, self.min_counts), self.max_counts)))

    def counts_to_angle(self, counts: float) -> float:
        """Inverse mapping, for interpreting encoder feedback as board angle."""
        if not self.measured:
            raise CalibrationError(
                f"axis on servo {self.servo_id} is not calibrated."
            )
        return (float(counts) - self.center_counts) / (self.sign * self.counts_per_rad)


@dataclass(frozen=True)
class ServoContract:
    """Policy action <-> board angle <-> servo counts, for both tilt axes."""

    roll: AxisCalibration = field(
        default_factory=lambda: AxisCalibration(servo_id=1)
    )
    pitch: AxisCalibration = field(
        default_factory=lambda: AxisCalibration(servo_id=2)
    )

    # Action [-1, 1] maps linearly onto +-max_tilt_rad. Start conservative and
    # widen only once the measured mapping and the travel limits agree.
    max_tilt_rad: float = math.radians(6.0)

    # A pose older than this is not evidence of where the board is.
    max_pose_age_s: float = 0.05

    # Servo settings in force when the calibration was measured. Recorded so a
    # later session can tell whether the numbers still apply.
    servo_config: dict = field(default_factory=dict)

    version: str = CONTRACT_VERSION

    @property
    def axes(self) -> tuple[AxisCalibration, AxisCalibration]:
        return (self.roll, self.pitch)

    @property
    def measured(self) -> bool:
        return all(axis.measured for axis in self.axes)

    # ---- action -> angle ---------------------------------------------------
    def action_to_angle(self, action) -> tuple[float, float]:
        """Map a policy action in [-1, 1]^2 to (roll, pitch) board angles.

        Non-finite input is rejected rather than clipped: NaN reaching the servos
        is a bug worth surfacing, not smoothing over.
        """
        values = tuple(float(v) for v in action)
        if len(values) != 2:
            raise ValueError(f"action must be 2 values, got {len(values)}")
        for value in values:
            if not math.isfinite(value):
                raise ValueError(f"action contains a non-finite value: {values}")
        clipped = tuple(min(max(v, -1.0), 1.0) for v in values)
        return (clipped[0] * self.max_tilt_rad, clipped[1] * self.max_tilt_rad)

    def angle_to_action(self, roll_rad: float, pitch_rad: float) -> tuple[float, float]:
        """Inverse of action_to_angle, for replaying recorded angles as actions."""
        return (
            min(max(roll_rad / self.max_tilt_rad, -1.0), 1.0),
            min(max(pitch_rad / self.max_tilt_rad, -1.0), 1.0),
        )

    # ---- angle -> counts ---------------------------------------------------
    def angles_to_counts(self, roll_rad: float, pitch_rad: float) -> tuple[int, int]:
        return (
            self.roll.angle_to_counts(roll_rad),
            self.pitch.angle_to_counts(pitch_rad),
        )
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

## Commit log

2026-08-04 Add calibrated board pose and marble vision
    [corner_tags_18mm_black.stl, corner_tags_18mm_white.stl]
2026-08-06 Add STS3215 servo stack, rescale maze to 256x226, replace policy contract
    Three strands of work, plus the consistency pass tying them together.
    Servos. A from-scratch FEETECH STS/SMS driver over pyserial, since no vendor
    SDK is installed. Byte order and framing were verified against FEETECH's own
    FTServo_Python rather than recalled: sms_sts passes protocol_end=0, so
    multi-byte values are little-endian, and Length counts parameters plus two.
    Two servos are on the bus at 1 Mbps as ids 1 and 2, switched from
    CONSTANT_SPEED to POSITION mode.
    Status bytes are servo health, not transaction failures. Treating a non-zero
    status as an error made both servos -- flagging an overvoltage at the time --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
    [maze_256x226.stl, maze_256x226_floor.stl, maze_256x226_walls.stl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]
2026-08-06 Measure the servo count->angle mapping against a BNO086 IMU
    servo_contract.py named tools/sysid_actuator.py as the thing that would fill it
    and that file did not exist, so every AxisCalibration had measured=False and
    angle_to_counts raised. It no longer does: roll 0.00474 deg/count, pitch
    0.00437, centres at counts 2350 and 2018, usable to +-1.4 deg on both axes.
    The measurement chain is new. An ESP32 streams the BNO086 game rotation vector
    at 200 Hz in 17-byte CRC-checked binary frames -- binary because this USB link
    is unreliable above 115200 and CSV quaternions would not fit inside it. Game
    rotation vector rather than the magnetometer-fused one, because two servos
    drawing current beside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
    [servo_calibration.json]
2026-08-06 Fix load decoding, widen the calibration, and measure operational backlash
    The calibration now spans the range it will actually be used over. A conditioned
    sweep across +-1200 counts fits a straight line to 1.99%/1.68% over 11.5 and
    12.2 degrees -- better relative accuracy than the earlier +-320-count sweep
    managed over 3 -- so the nonlinear AxisCalibration that looked inevitable is not
    needed. Roll 0.00487 deg/count, pitch 0.00502, centres 2215 and 2053,
    max_tilt +-4.0 deg against calibrated headroom of +-5.42 and +-5.78.
    PRESENT_LOAD was decoded with the wrong sign bit. Its direction lives in bit 10,
    not bit 15, so every load in one direction read as 1024 plus its true value.
    "The plate i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
    [servo_calibration.json, servo_travel_limits.json]
2026-08-06 Feed the lost motion forward: tilt control layer
    tag_vision/control/tilt.py turns a commanded board angle into servo counts with
    the backlash compensated. Measured on the rig, commanding 0/+2/0/-2 deg
    repeatedly:
    roll mean |error| 0.876 -> 0.261 deg
    pitch mean |error| 0.427 -> 0.258 deg
    spread at 0 deg 1.094 -> 0.080 (roll), 0.951 -> 0.086 (pitch)
    Deliberately not a PID. About 100 ms of the step latency is electrical and
    irreducible, which caps a stable feedback loop near 0.2-0.3 Hz, too slow to help
    a policy that is already reacting. Meanwhile the two dominant errors are both
    deterministic and both in a calibration file: the gain, and ~1.35 deg of lost
    motion on reve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
2026-08-10 Build real-camera planning and model-based RL
    [directional_motor.json, servo_calibration.json]
